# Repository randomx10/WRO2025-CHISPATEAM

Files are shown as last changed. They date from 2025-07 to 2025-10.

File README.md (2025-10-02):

# CHISPA team – WRO 2025
---
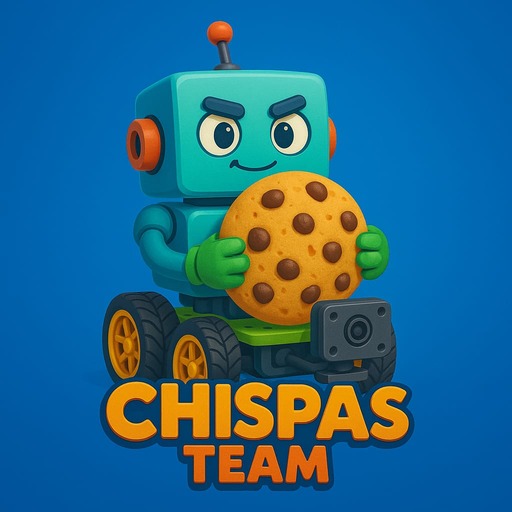
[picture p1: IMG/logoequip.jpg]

---
Welcome to the official repository of the **CHISPA team**!  
This space contains all the resources, schematics, models, photos, and code developed for our participation in the **Future Engineers** challenge at the **World Robot Olympiad 2025**.

>[!NOTE]
>
>Here you’ll find detailed information about the design, functionality, and technical documentation of our autonomous vehicle.
>

---

## 📸 Team Photos

Below are two images that reflect our team’s identity:

| 📷 Official Photo | 😄 Fun Photo |
|---|---|
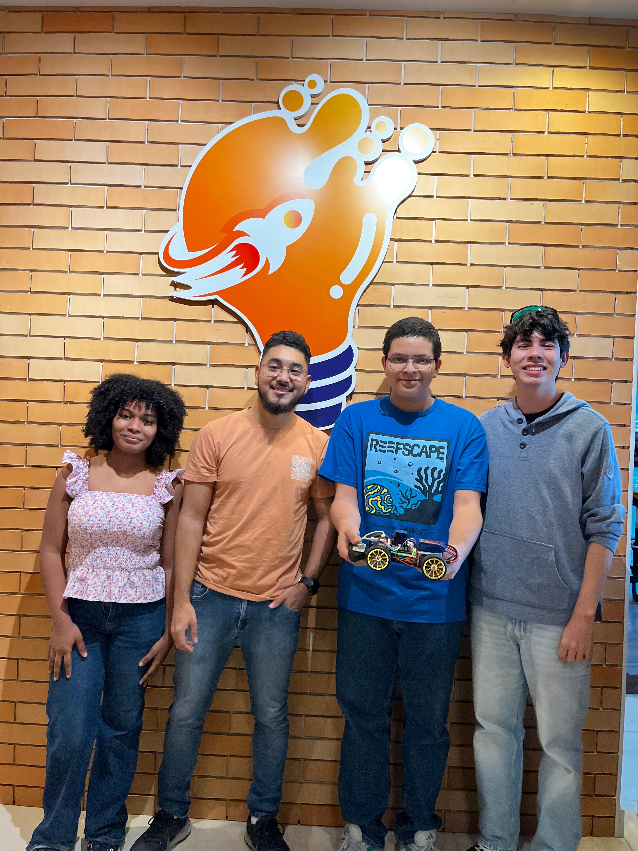
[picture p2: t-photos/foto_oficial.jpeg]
Official team photo
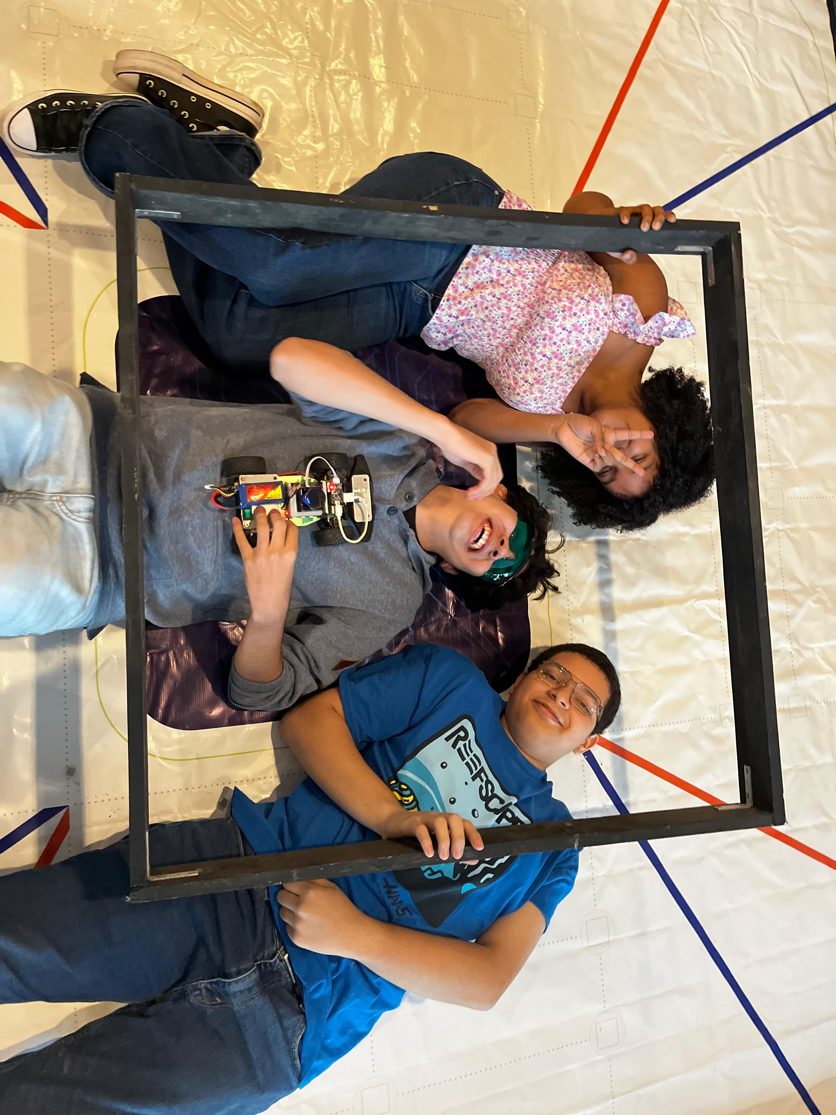
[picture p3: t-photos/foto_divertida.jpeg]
Fun team photo
|  |  |

---

## 💻 Github folder structure/overview
```
🛜 WRO2025-CHISPATEAM
├── 📁 IMG # Images for internal use of the github
├── 📁 docs # Explanation of components/hardware/software
├── 📁 models # 3D parts ready to print
├── 📁 schemes # Schematic diagram of the robot, along with individual component images
├── 📁 src # Source code that powers the robot controllers
├── 📁 t-photos # Team pictures, the funny one and the official
├── 📁 v-photos # All angles of the robot
├── 📁 video # Videos of the robot preforming competition rounds
├── 📄 README.md # Introduction
├── 📄 LICENSE # AGPL 3.0 License Copy, prohibiting copy on other repositories without crediting the respective authors.
├── 📄 equipochis.jpeg # Official team image
```
---

## 🚗 Vehicle View

Here you can see the full design of the vehicle from every angle. This detailed view helps to understand the layout of components and overall structure.

| Front | Back | Left |
|---|---|---|
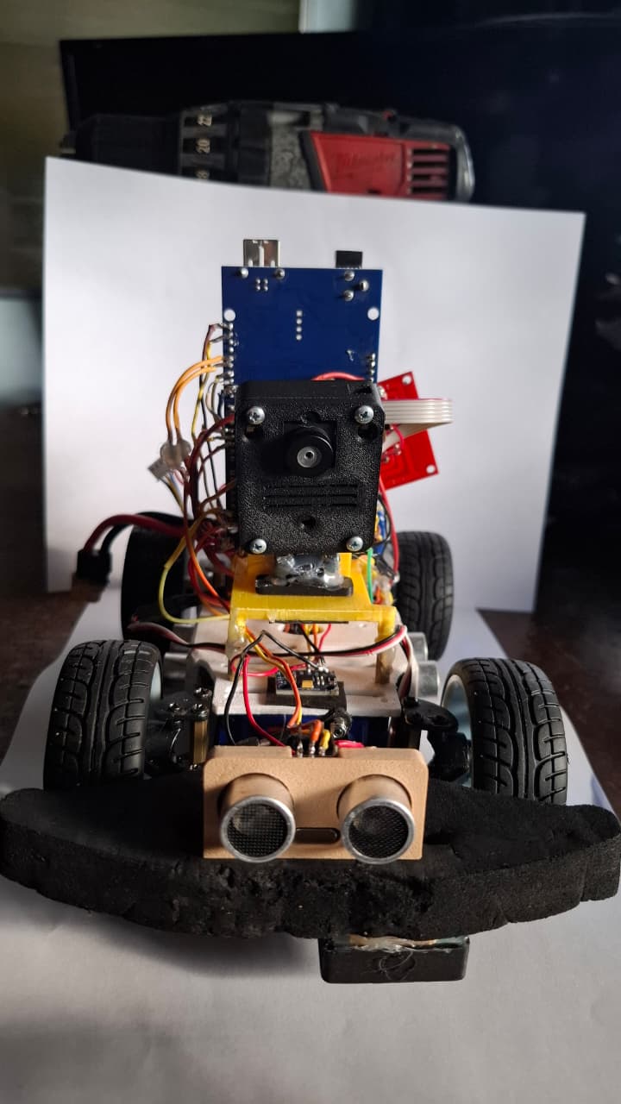
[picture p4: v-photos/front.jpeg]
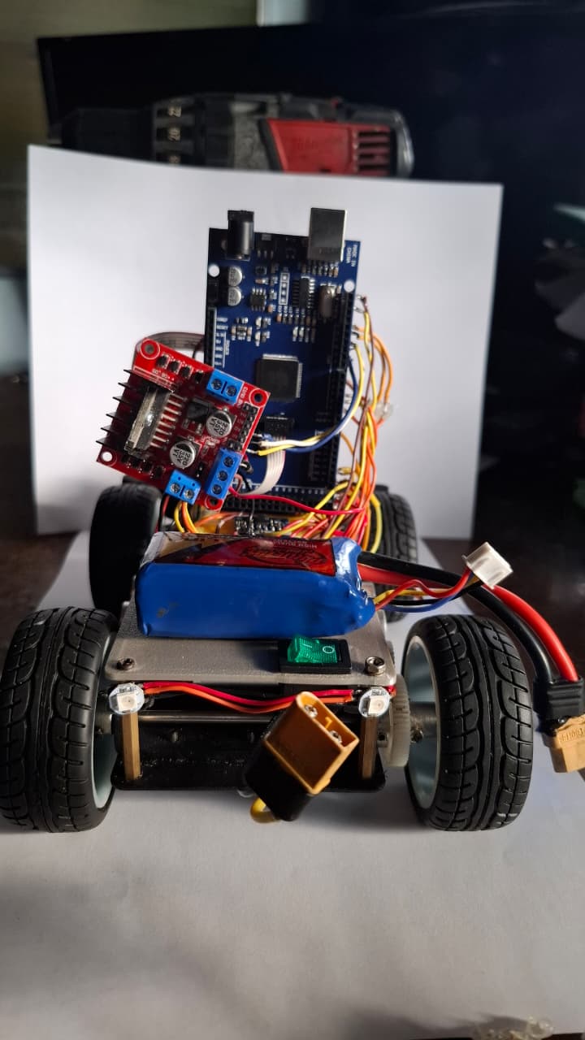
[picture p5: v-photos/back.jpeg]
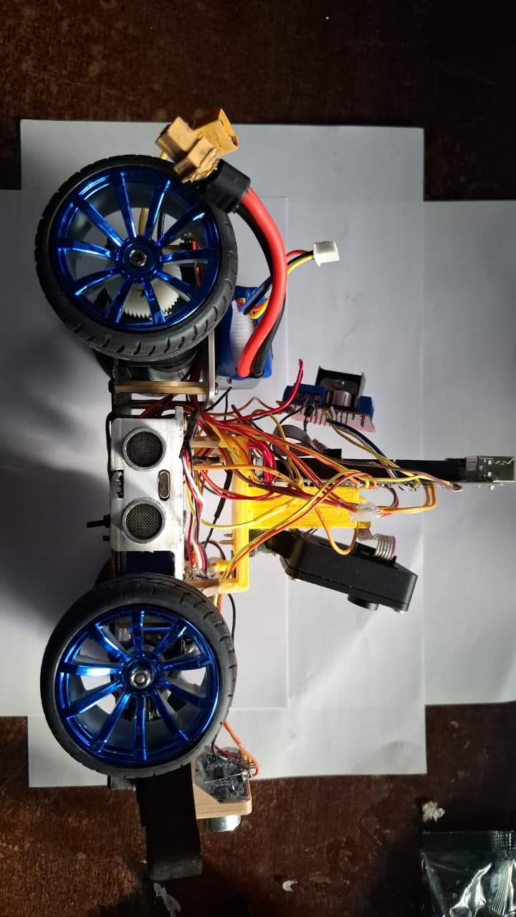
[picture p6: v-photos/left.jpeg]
|  |  |  |

| Right | Top | Bottom |
|---|---|---|
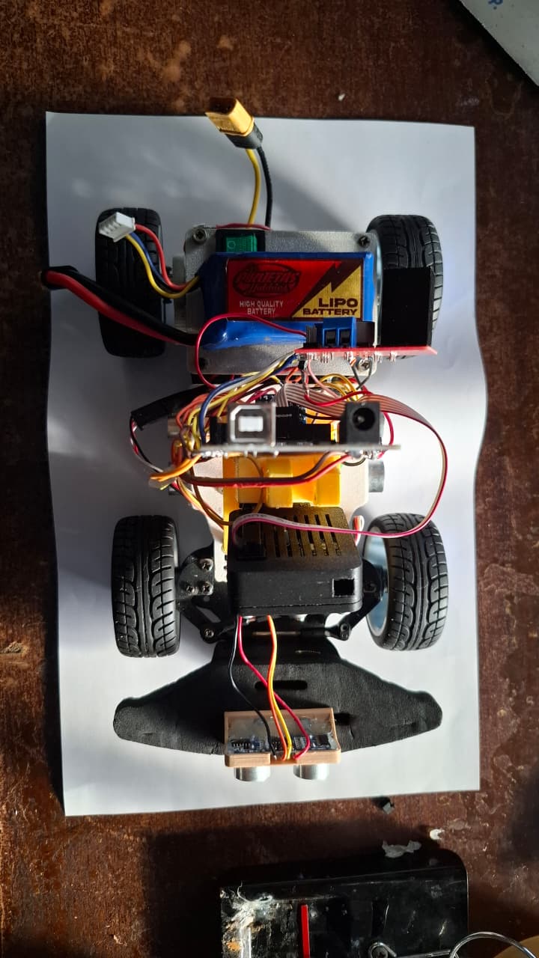
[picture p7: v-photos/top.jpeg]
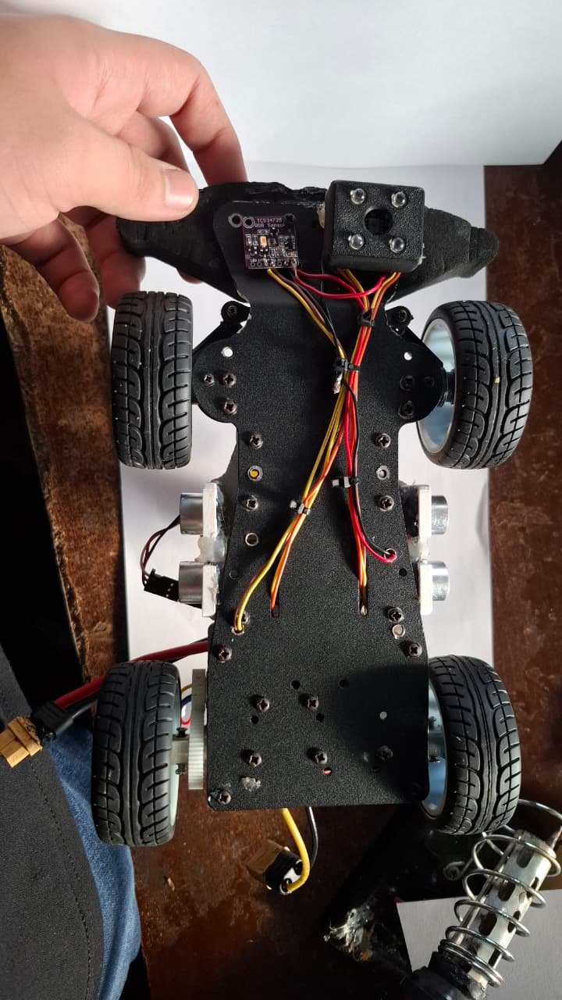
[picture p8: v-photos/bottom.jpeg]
|  |  |  |

---

<h2 align="left">🧠 Electromechanical Components & Wiring</h2>

<table>
  <tr>
    <td align="center">
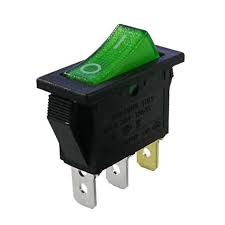
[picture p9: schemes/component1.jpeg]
      <br>
      <b>3-Pin Switch</b>
    </td>
    <td align="center">
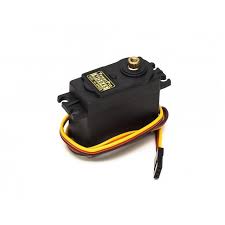
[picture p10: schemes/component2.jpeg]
      <br>
      <b>Servo MG945</b>
    </td>
    <td align="center">
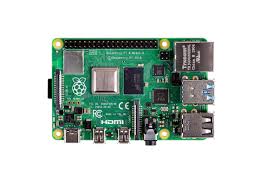
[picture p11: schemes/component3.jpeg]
      <br>
      <b>Raspberry Pi 4</b>
    </td>
  </tr>

  <tr>
    <td align="center">
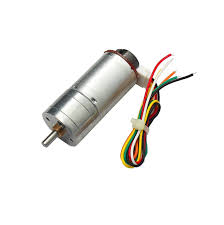
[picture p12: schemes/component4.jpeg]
      <br>
      <b>JGA25-370 Motor</b>
    </td>
    <td align="center">
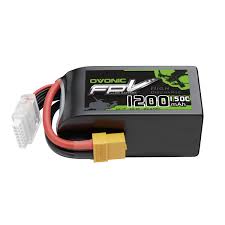
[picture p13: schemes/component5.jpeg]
      <br>
      <b>LiPo Battery 1200mAh 12V</b>
    </td>
    <td align="center">
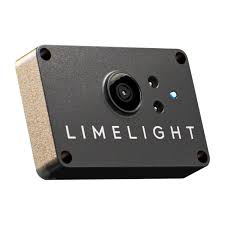
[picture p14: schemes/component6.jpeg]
      <br>
      <b>Limelight 3A</b>
    </td>
  </tr>

  <tr>
    <td align="center">
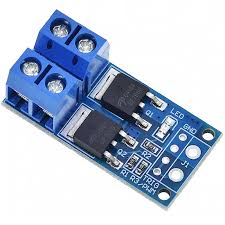
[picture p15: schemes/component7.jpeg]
      <br>
      <b>HC-SR04 Sensor</b>
    </td>
    <td align="center">
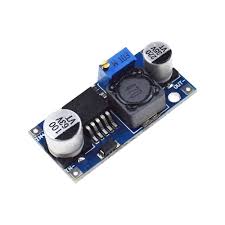
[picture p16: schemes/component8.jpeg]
      <br>
      <b>L298N Motor Driver</b>
    </td>
    <td align="center">
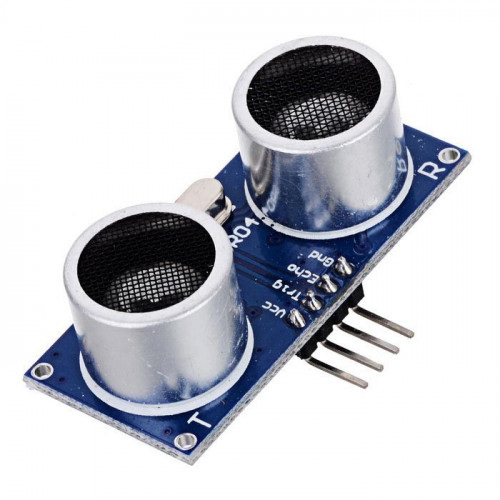
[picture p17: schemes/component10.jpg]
      <br>
      <b>HC-SR04 Sensor</b>
    </td>
  </tr>

  <tr>
    <td align="center">
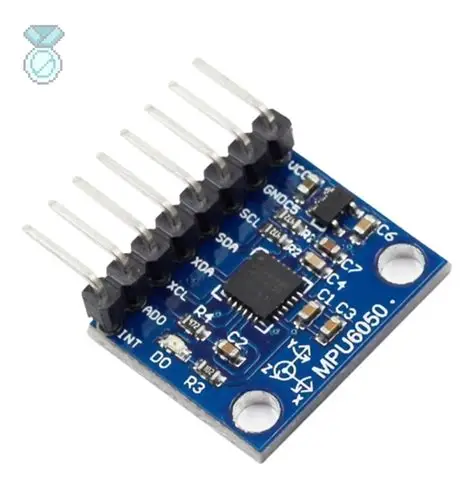
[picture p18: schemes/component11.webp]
      <br>
      <b>GY-251 Gyroscope</b>
    </td>
    <td align="center">
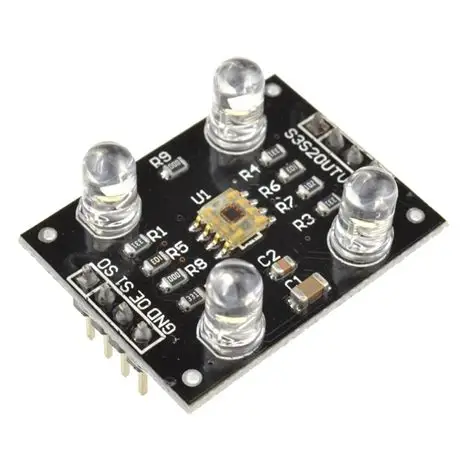
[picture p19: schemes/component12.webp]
      <br>
      <b>TCS3200 Color Sensor</b>
    </td>
    <td align="center">
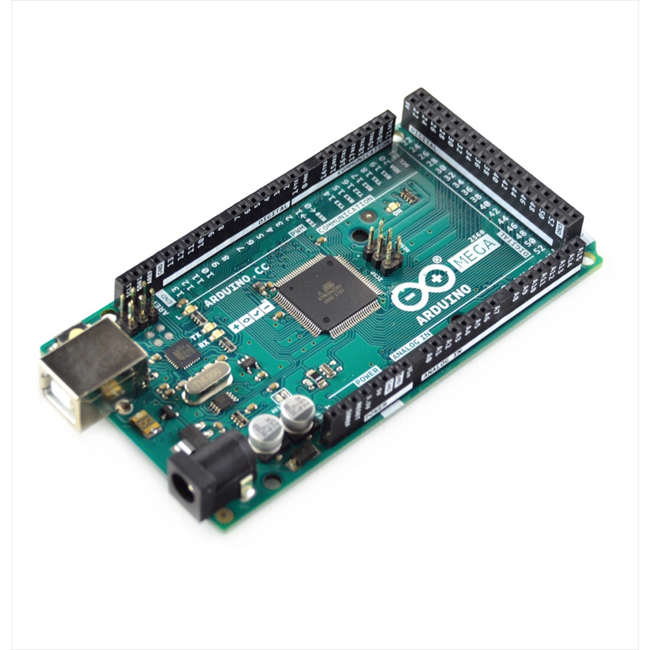
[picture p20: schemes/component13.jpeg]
      <br>
      <b>Arduino Mega</b>
    </td>
  </tr>
</table>

---

### Challenge Overview
The WRO 2025 Future Engineers category challenges student teams to design, build, and program a fully autonomous vehicle capable of navigating a dynamic and randomized racetrack. This vehicle must use sensors, computer vision, and advanced control algorithms to complete multiple laps with high precision. The challenge concludes with a demanding parallel parking maneuver requiring accuracy and control within a confined space 🚗🤖.

### Competition Format
- 🏁 **Open Challenge:** Complete three laps on a track featuring randomly placed inner walls. The vehicle should maintain stable trajectory control, demonstrating robustness and consistent performance throughout.  
- 🚦 **Obstacle Challenge:** Complete three laps while detecting and reacting to randomly placed red and green traffic markers:  
  - 🟥 Red markers require the vehicle to keep to the right side of the lane.  
  - 🟩 Green markers require the vehicle to keep to the left side of the lane.  
  Upon finishing these laps, the vehicle must locate the designated parking zone and execute a precise parallel parking maneuver within limited space 📐.  
- 📑 **Documentation:** Teams must maintain a public repository documenting all aspects of their engineering process, vehicle design, software development decisions, and source code. This provides transparency and demonstrates reproducibility and improved learning.

### Scoring & Evaluation
Judging is based on the following criteria:  
- **Precision:** Accuracy in lap completion, obstacle handling, and parking.  
- **Technical quality:** Clarity, organization, and completeness of project documentation and source code.  
- **Speed:** Total time to complete the challenge, balanced against precision.  
- **Innovation and robustness:** Judges value effective engineering decisions, software reliability, and creative solutions that enhance autonomous performance 💡⚙️.

### Robot Performance: Speed and Maneuvering
Our vehicle's average velocity on straight sections is approximately **1.2 meters per second**, enabling fast and stable lap completion. In contrast, during turns and cornering maneuvers, the speed reduces to about **1.7 meters per second** on average to ensure stable handling and precise navigation. The control algorithm dynamically adapts motor power and steering angles based on sensor feedback, maintaining optimal traction and avoiding drift even in tight curves.

---

### Key Components

| Component | Description |
| --- | --- |
| **Raspberry Pi 4** | Central processor for vision, decision logic, and sensor fusion; runs Python services and serial link to Arduino. |
| **Arduino MEGA** | Real‑time layer for PWM motor drive, servo steering, and ultrasonic reads; ensures deterministic control. |
| **Limelight 3A** | High‑performance vision module adapted for target/color detection to assist navigation and alignment. |
| **HC‑SR04 Ultrasonic Sensors (front + side)** | Proximity sensing and wall following; foam collars reduce ground reflections. |
| **GY‑251 (MPU6050)** | IMU for heading stabilization and consistent 90° turns; mounted near center of gravity. |
| **TCS3200 Color Sensor** | Floor color detection; calibrated for consistent orange/blue under fixed lighting. |
| **L298N Motor Driver** | Dual H‑bridge for direction and PWM speed control; onboard heatsink improves thermal headroom. |
| **JGA25‑370 Gear Motors** | Drive motors with high torque at low RPM for precise maneuvers and climbs. |
| **Servo MG945** | Metal‑gear steering servo; mounted on custom 3D bracket to avoid horn slip. |
| **LiPo 12 V 1200 mAh** | Main power source; sized for match duration with headroom for peaks. |
| **LM2596 Buck Regulator (5 V)** | Stable 5 V rail for logic and sensors; tuned under load to prevent brownouts. |
| **3D‑Printed Chassis** | Lightweight, custom structure with rigid mounts and protected cable routing. |

### Strengths and Innovations
- **Advanced vision processing:** Real-time color and shape detection for robust environment understanding.  
- **Precise sensor fusion:** Combining data from IMU, ultrasonic sensors, and camera enables stable navigation under varying conditions.  
- **Dynamic speed control:** Adapting velocity in straight lines versus curves increases efficiency without sacrificing control.  
- **Modular design:** Easily upgradable hardware and software architecture supports iterative development and rapid testing.  
- **Comprehensive documentation:** Detailed instructions and open-source code improve learning and foster community collaboration.

---

### Index
- [Challenge Overview](#challenge-overview)  
- [Competition Format](#competition-format)  
- [Scoring & Evaluation](#scoring--evaluation)  
- [Robot Performance](#robot-performance-speed-and-maneuvering)  
- [Key Components](#key-components)  
- [Strengths and Innovations](#strengths-and-innovations)  

### 📊 Wiring Diagram

Below is the full electromechanical schematic that shows how everything is connected:

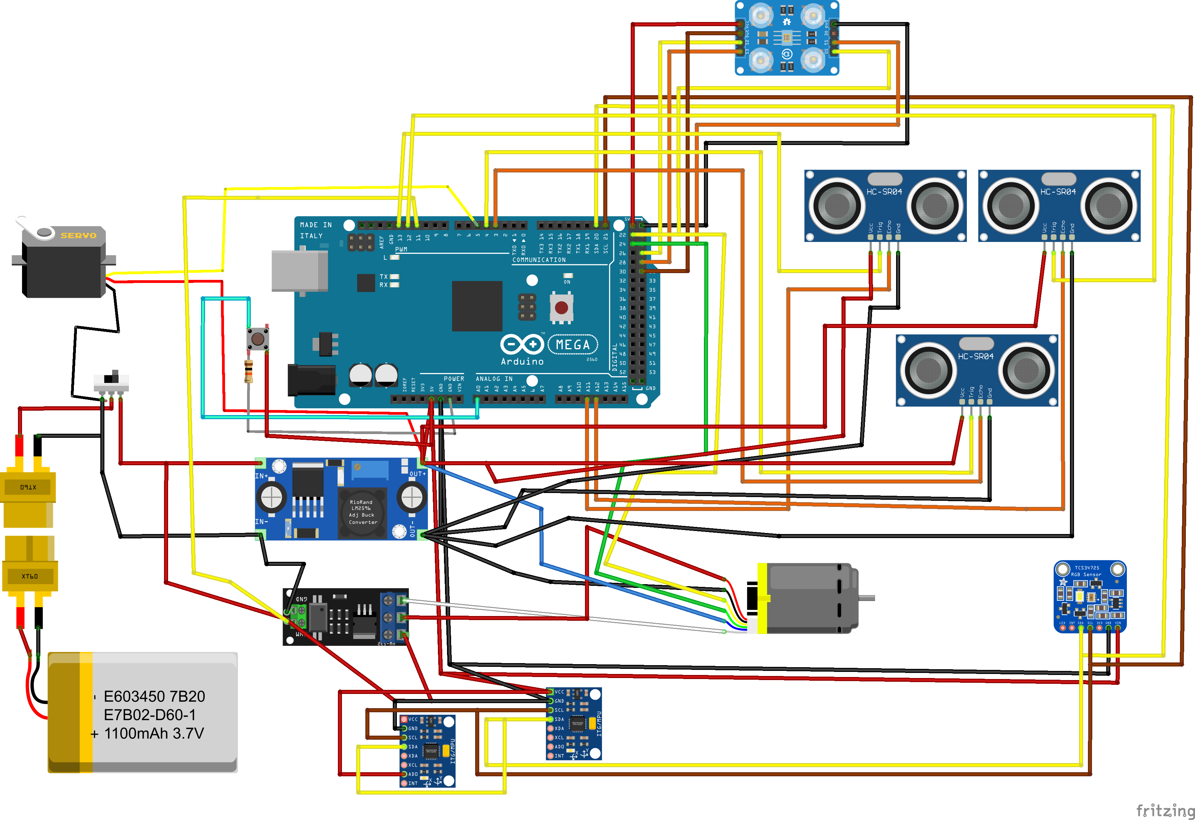
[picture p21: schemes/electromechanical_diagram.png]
Wiring Diagram


> You can find this image and other versions in the [`schemes`](schemes/) folder.

---

## 🔧 Components and Sensor Integration

Our robot was built using a mix of modular components from an existing kit and custom-designed 3D printed parts to fit the needs of the Future Engineers challenge. This hybrid approach allowed us to maximize the strengths of reliable, pre-tested hardware while also tailoring specific solutions for unique tasks in the mission. Below is a highly detailed breakdown of all the components we used, their technical roles, the integration logic, issues we faced, and how we adapted to overcome them. Our documentation not only reflects the functionality of each part, but also highlights the engineering decisions made throughout the robot’s development.

### 🔋 Power Supply 

**LiPo Battery 1200mAh 12V**

- Powers the entire robot system, ensuring both mobility and computational processing are supported throughout the match.  
- Provides stable power output for the motors, sensors, Raspberry Pi, and Arduino.  
- We used a voltage regulator to avoid current spikes and protect delicate components like microcontrollers.  
- This solution helped mitigate early issues we faced with sudden shutdowns during intensive operations.  
- A battery monitor was also incorporated to measure real-time voltage and alert us when levels dropped too low.

### 💻 Main Controllers

**Raspberry Pi 4**

- Acts as the central processing hub of the robot.  
- Responsible for image processing, decision-making logic, and managing sensor data.  
- Runs Python scripts to interpret input from the Limelight and communicates with the Arduino through a serial interface.  
- Its high-speed processing capabilities allow us to manage simultaneous tasks like pathfinding, obstacle avoidance, and turn correction.  

**Arduino MEGA**

- Controls low-level tasks such as PWM motor control and real-time sensor readings (e.g., ultrasonic distance, servo movements).  
- Acts as a reliable bridge for deterministic behavior in the hardware layer.  
- The division of responsibilities between Pi and Arduino helped us balance computational load and reduce latency.  
- Simplifies hardware debugging and guarantees fast, responsive control signals.

### 👁️ Object Detection & Tracking

**Limelight 3A**

- Originally designed for FRC robots, this powerful camera system was adapted to fit our smaller robot.  
- Detects and locks onto specific colored or shaped objects.  
- Enables autonomous navigation by marking visual targets and aligning accordingly.

**Challenges:**  
- Required a well-lit and consistent environment to provide reliable data.  
- We adjusted the robot’s onboard lighting and modified thresholds in the Limelight software to improve reliability.  
- Integrated a protective mount and anti-vibration dampers to stabilize image input.

### 🚫 Removed Component

**LDrobot Lidar LD19**

- Initially selected for real-time SLAM and environment scanning.

**Why We Stopped Using It:**  
- Provided unstable and inconsistent results in small, confined spaces.  
- Difficulty detecting nearby walls and objects due to reflection noise.  
- Calibration proved time-consuming and performance did not justify complexity.

**Our Solution:**  
- Replaced with strategically placed ultrasonic sensors and a reliable gyroscope to manage spatial awareness with much greater efficiency.  
- This switch greatly improved the consistency and reduced computational load.

### 🔄 Motor Control

**L298N Motor Driver**

- Dual H-Bridge driver that allows for direction control and PWM-based speed adjustment.  
- Initial controller suffered overheating; L298N offered a robust and thermally safer alternative.  
- Equipped with a built-in heat sink to improve heat dissipation as this controller gets hot quickly.

**JGA25-370 Gear Motors**

- Provides strong torque and reliable performance, especially during turns and ramp climbs.  
- Compatible with our power source and robust enough for repeated high-load operations.  
- Low RPM ensures accurate control in precision-based movement challenges.

**Servo MG945**

- Handles the turning of the robot left/right.
- Durable metal gears ensure precision and long operational lifespan.  
- Integrated with custom 3D-printed brackets to prevent misalignment and slippage.

### 🔊 Sensors for Navigation and Detection

**HC-SR04 Ultrasonic Sensors**

- Function: Detect distance to nearby objects and walls.  
- Technical Accuracy: ~3mm, max range 4m.  
- Usage: Placed on both front and side of robot to measure proximity and assist in avoiding wall collisions.  
- These sensors play a critical role in maintaining correct lane alignment and determining when to make turns.  
- We added foam dampers around the sensors to reduce interference from ground reflections.

**GY-251 Accelerometer + Gyroscope (MPU6050-based)**

- Function: Detects angular velocity and tilt.  
- Usage: Guides the robot’s heading during turns and confirms straight-line travel.  
- Essential for making consistent 90° turns and for recalibration during complex movements.  
- Mounted at the center of gravity to reduce noise and increase accuracy.

**TCS3200 Color Sensor**

- Function: Reads floor tile colors to guide robot’s path.

**Issues and Solutions:**  
- One unit had significant lag and failed to detect color transitions in motion.  
- Another sensor misidentified multiple colors and only read orange with high confidence.  
- Calibration trials under consistent lighting; replaced the malfunctioning unit with a higher-quality clone.

**Accuracy Reference (sourced from mixed data):**

| Color  | Accuracy (%) |
|---|---|
| Red | 92% |
| Green  | 89% |
| Blue | 94% |
| Yellow | 87% |
| Orange | 96% |
| White  | 91% |
| Black  | 88% |

## (see [docs](https://github.com/randomx10/WRO2025-CHISPATEAM/tree/main/docs) for more information)

### 🔌 Power & Regulation

**LM2596 Voltage Regulator**

- Converts 12V from LiPo battery to stable 5V required by sensors and controllers.  
- Fine-tunable and heat-resistant, preventing power-related failure during operation.  
- Easy to replace and adjust for different output requirements during testing phases.

**3-pin Toggle Switch**

- Allows safe, manual powering of the entire robot without direct battery disconnection.  
- Placed on the back panel for convenient access and safety during handling.

---

## 🛠️ Robot Construction Guide

This guide explains how to assemble the chassis, drivetrain, electronics, and software for the WRO2025-CHISPATEAM robot. Each step is short and practical so the build can be reproduced reliably.

### Step 1: Assemble the steering system ⚙️
- Print the steering-related 3D parts located in `/models` (servo bracket, horn spacer, steering hubs).  
- Mount the Servo MG945 securely to the chassis using screws and the 3D-printed bracket; verify there is no flex under load.  
- Connect the steering axle/linkage to the MG945 horn with a proper coupler; ensure full sweep without binding.  
- Install the front steering hubs and verify the arm moves freely and does not collide with the chassis or wiring.  
- Center the servo (neutral PWM) and align wheels to straight-ahead before tightening horn screws.

### Step 2: Assemble the powertrain 🚗
- Fix the JGA25-370 gear motors onto their 3D-printed motor mounts; use thread-lock where appropriate to prevent loosening.  
- Couple each motor shaft to the driven axle/gear as per the mount design; confirm no eccentricity or wobble.  
- Check clearance so gears and wheels rotate without rubbing the chassis under load.

### Step 3: Mount the electronics 🔌
- Attach the LiPo 12V 1200 mAh battery in a protected position; add foam or straps to avoid vibration and impacts.  
- Install the LM2596 regulator and set a stable 5 V output for logic and sensors; verify with a multimeter before connecting boards.  
- Place the Raspberry Pi 4 and Arduino MEGA on standoffs; route power via LM2596 and keep high-current lines separate from signal lines.  
- Mount the Limelight 3A on a rigid, slightly angled bracket; add anti‑vibration pads to stabilize the image.  
- Position the HC‑SR04 ultrasonic sensors (front and side) with a clear field of view; add small foam skirts if floor reflections are an issue.  
- Mount the GY‑251 (MPU6050) close to the robot’s center of gravity, flat and isolated from motor vibrations.

### Step 4: Attach the wheels 🛞
- Mount front wheels on the steering hubs; ensure free rotation and zero lateral play.  
- Install rear wheels on the driven axle linked to the JGA25‑370; add spacers or washers to maintain alignment.  
- Spin each wheel by hand and listen for rubbing or gear mesh noise; adjust until smooth.

### Step 5: Preparation for operation ✅
- Check that the chassis is balanced and that cable runs are secured away from moving parts.  
- Verify all screw joints are tight; re‑center the servo and confirm steering endpoints do not stall the MG945.  
- Power on with a current‑limited supply the first time; confirm 5 V rail remains stable under sensor and servo load.

### Step 6: Software setup 💻
- On Raspberry Pi 4, deploy the Python services for vision (Limelight integration), decision logic, and Pi↔Arduino serial link.  
- On Arduino MEGA, upload the low‑level firmware handling PWM motor control, servo steering and real‑time sensor reads.  
- Test the serial protocol: the Pi should stream targets/commands, the MEGA should acknowledge and actuate deterministically.  
- Calibrate sensors:  
  - Limelight thresholds/lighting profile.  
  - Ultrasonic baselines and timeouts.  
  - MPU6050 gyro bias at rest.  
- Run a dry test on blocks (wheels off the ground) to validate direction, steering sign, and emergency stop.

---

## 🧠 How It All Works Together

Our robot was developed for the WRO 2025 Future Engineers Challenge, a task requiring navigation of a color-coded maze, obstacle avoidance, and accurate maneuvering. To achieve this, we implemented a layered control strategy:

**Color Sensing:**  
- The robot follows a line/path system on the floor, detecting color patterns using the TCS3200.  
- Decisions (turns, stops, or interactions) are triggered based on detected color.  
- Logic is reinforced with timeouts and counters to avoid misreads from transient reflections.

**Obstacle Avoidance:**  
- HC-SR04 sensors measure distances in real-time.  
- On detecting an object or wall within a threshold, the robot adjusts trajectory accordingly.  
- In edge cases, the gyroscope is consulted to determine alternative safe paths.

**Turning & Direction Control:**  
- Using GY-251 gyro data, we ensure consistent 90° turns.  
- Helps correct drift and ensures we remain aligned with map paths.  
- Combined with encoder data for better positional awareness.

**Central Coordination:**  
- The Raspberry Pi processes high-level logic and forwards simplified instructions to the Arduino.  
- This modular separation allows real-time reaction to environmental data while executing long-term movement plans.  
- Logs are stored locally for later debugging and performance analysis.

**Structural Customization:**  
- We modified kit-based chassis with 3D-printed mounts for better sensor placement and airflow.  
- This helped avoid overheating and mechanical misalignments during long test sessions.  
- The design is compact yet expandable, making it ideal for future missions.

**Component Testing and Iteration:**  
- Every part of the robot went through unit testing and stress evaluation.  
- We documented all observed limitations and iteratively improved sensor placement and code logic.  
- Testing environments included both simulated and real-field trials.

By overcoming major hurdles like sensor inconsistency, voltage fluctuations, and Lidar misreadings, we developed a system that is adaptive, stable, and ready to complete the mission using components we understand deeply. Our documentation, design, and testing reflect a clear engineering vision with flexibility and resilience at its core.

In summary, the robot reflects a balance between innovation and practicality — leveraging what we have while adapting smartly to meet the demands of a complex and evolving challenge. Our engineering choices were made with precision, and the modular approach means the robot is easy to repair, extend, and reconfigure if necessary. We’re proud of its development and look forward to testing it further on the competition field.

<h2 align="left">🧩 3D Printed Parts</h2>

<p>
In this section, you will find the 3D printed components that were essential to the design and functionality of our robot. These pieces were specifically created to optimize vision and structural support while keeping the overall weight of the robot low and ensuring precise alignment of key systems.
</p>

<table>
  <tr>
    <td align="center">
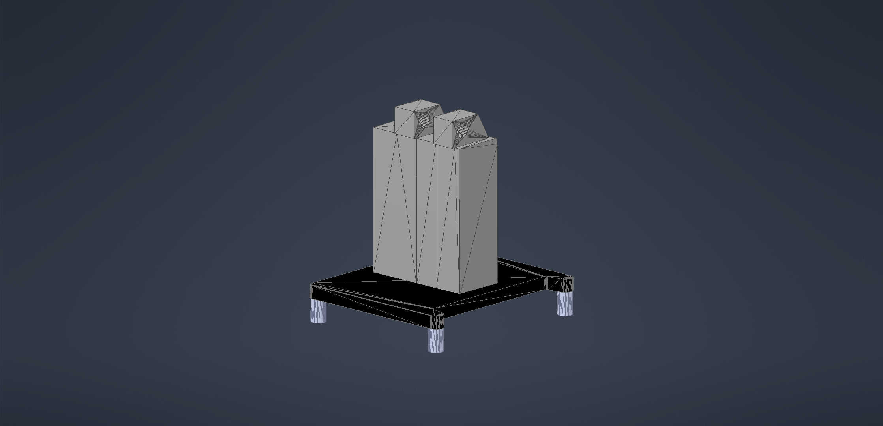
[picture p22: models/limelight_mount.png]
      <br>
      <b>Limelight Mount</b><br>
      One of the most important printed pieces is the mount for the Limelight camera. We designed it to keep the vision system stable and in the right position to detect the traffic signals and track targets efficiently. The angle was carefully adjusted to increase field of view and reduce blind spots. It’s lightweight but solid enough to hold the camera steady, even during fast movements. This improvement helped us gain more accuracy and align much better with our objectives.
    </td>
    <td align="center">
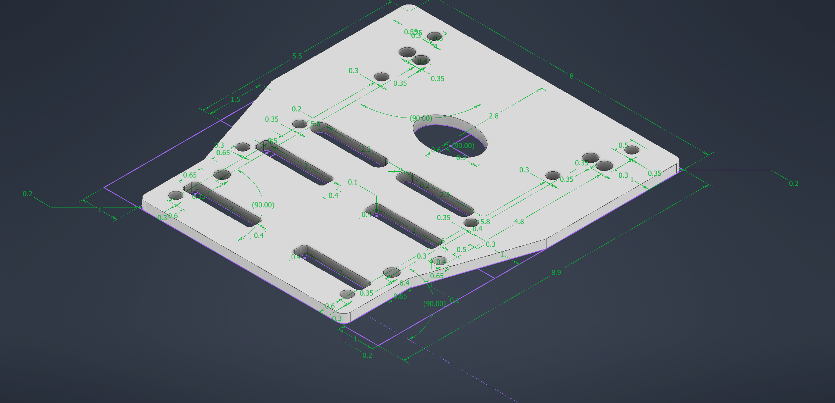
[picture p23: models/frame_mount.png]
      <br>
      <b>Top Chassis Support</b><br>
      This structural support is placed on the top part of the chassis and was designed to hold sensors, wiring, and additional modules in place. One of the main goals was to improve the internal layout of the robot, keeping everything organized and making maintenance easier. It also adds an extra layer of protection to the internal electronics. This part was printed using strong filament to ensure rigidity and durability, without affecting the balance of the robot.
    </td>
  </tr>
</table>

<p>
Both of these components were modeled in CAD software and tested through multiple iterations before reaching the final versions. The printing process took several hours for each, but the result was worth the effort, as they improved our performance significantly during testing and competition.
</p>

## 🎯 Competition Challenges

<table align="center" border="1" cellspacing="0" cellpadding="8">
  <tr>
    <!-- Open Challenge card -->
    <td valign="top" width="360">
      <div>🔗 Open Challenge</div>
      <div align="center">
        Open Challenge - image
      </div>
      <div align="center">
        <a href="https://www.youtube.com/watch?v=e4CDzBtp_W8">Watch Open Challenge Round</a>
      </div>
    </td>
  </tr>
</table>

##  Track Performance

Our vehicle is tuned for stable, repeatable lap times by adapting speed and steering to the track segment: it targets approximately 1.2 m/s on straight sections and about 1.7 m/s through turns, with smooth ramp-up and ramp-down around each corner to preserve traction and heading control.

#### Key metrics
- Straight-line speed: ~1.2 m/s, with high-frequency heading corrections to stay centered in the lane.
- Cornering speed: ~1.7 m/s, limited by lateral acceleration and line-of-sight constraints near inner walls.
- Transitions: short acceleration/brake ramps before/after the apex to avoid over/understeer.
- Stability: yaw-based PD keeps the car aligned; exit lines are corrected quickly after each corner.

| Parameter | Straights | Turns |
| :--- | :--- | :--- |
| Target speed | ~1.2 m/s | ~1.7 m/s |
| Primary control | Gyro-based PD (yaw)  | Gyro PD + lateral accel cap |
| Acceleration | Smooth, traction-first | Suppressed at apex, recover on exit |
| Corrections | Small, high-rate | Moderate, radius-dependent |

#### How it works
- Pre-aiming into corners: the controller slightly reduces speed and applies steering in advance so the vehicle is already stable at corner entry.  
- Lateral acceleration limiter: while cornering, the controller caps lateral demand; if heading error rises, it briefly trims speed to regain grip.  
- Corner exit: past the apex, the system straightens steering and restores speed to the 1.2 m/s target, prioritizing a clean trajectory over peak thrust.  
- Line and wall biasing: near inner walls, the lateral offset is adjusted to keep safe clearance without adding unnecessary steering oscillations.

#### Measurement assumptions
- Test track uses standard surface and markings; tires are calibrated and warmed up.
- The 1.2 m/s (straights) and 1.7 m/s (turns) targets can vary slightly with temperature, tire wear, and lighting.
- Practice sessions should log section times to verify consistency; comparing segment splits is recommended for tuning.

> [!WARNING]
>
> This program is distributed in the hope that it will be useful,
> but WITHOUT ANY WARRANTY; without even the implied warranty of
> MERCHANTABILITY or FITNESS FOR A PARTICULAR PURPOSE.
> If any portion of this program is to be used in any other application, you must
> credit the respective authors and provide a copy of the AGPL 3.0 License.
> [More information on LICENSE.](https://github.com/randomx10/WRO2025-CHISPATEAM/blob/main/LICENSE)
>

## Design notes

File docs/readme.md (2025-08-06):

# 🤖 Project CHISPA: Components & Sensor Integration

Welcome to the documentation for **Project CHISPA**, our robot designed for the WRO 2025 Future Engineers Challenge! This README provides an in-depth look at the hardware that powers our autonomous system, detailing each component's role, integration logic, and the engineering challenges we overcame during development.

Our robot leverages a **hybrid approach**, combining robust modular components from an existing kit with custom-designed 3D-printed parts. This strategy allowed us to harness the reliability of pre-tested hardware while creating tailored solutions for the mission's unique demands.

## 🗺️ Table of Contents

1. [🔋 Power Supply]

2. [💻 Main Controllers]

3. [👁️ Object Detection & Tracking]

4. [🚫 Removed Component: Lidar]

5. [🔄 Motor Control]

6. [🔊 Sensors for Navigation and Detection]

7. [🔌 Power & Regulation]

8. [🧠 How It All Works Together]

## 🔋 Power Supply

The backbone of our robot's operation, ensuring consistent power delivery to all systems.

* **LiPo Battery 1200mAh 12V**

  * **Role:** Powers the entire robot, supporting both mobility and computational processing throughout the mission.

  * **Integration Logic:** Provides stable power output for motors, sensors, Raspberry Pi, and Arduino.

  * **Key Feature:** We Integrated a **voltage regulator** to prevent current spikes and protect delicate components, it is the LM2596 which provides us with stable 12V to 5V for the raspberry pi, arduino, servo and sensors.
 
  * **Issue & Solution:** Mitigated early issues of sudden shutdowns during intensive operations. A **battery monitor** was incorporated for real-time voltage measurement and low-level alerts.

## 💻 Main Controllers

The brains and brawn, orchestrating high-level decision-making and low-level hardware control.

* **Raspberry Pi 4**

  * **Role:** Central processing hub. Responsible for **image processing**, **decision-making logic**, and **sensor data management**.

  * **Integration Logic:** Runs Python scripts to interpret input from the Limelight and communicates with the Arduino via a serial interface.

  * **Capabilities:** High-speed processing for simultaneous tasks like pathfinding, obstacle avoidance, and turn correction.

  * **Enhancements:** Includes an **external cooling fan** and **heat sinks** for optimal temperature maintenance during extended operations.

* **Arduino MEGA**

  * **Role:** Controls low-level tasks such as **PWM motor control** and **real-time sensor readings** (e.g., ultrasonic distance, servo movements).

  * **Integration Logic:** Acts as a reliable bridge for deterministic behavior in the hardware layer such as the drivetrain itself (servomotor and engine).

  * **Benefits:** Division of responsibilities with the Pi balances computational load and reduces latency. Simplifies hardware debugging and guarantees fast, responsive control signals.

## 👁️ Object Detection & Tracking

Our robot's eyes, enabling autonomous navigation through visual target acquisition.

* **Limelight 3A**

  * **Role:** Powerful camera system adapted from FRC robots to detect and lock onto specific colored or shaped objects.

  * **Usage:** Enables autonomous navigation by marking visual targets and aligning the robot accordingly.

  * **Challenges:**

    * Required a well-lit and consistent environment for reliable data.

    * **Solution:** Adjusted the robot’s onboard lighting and modified thresholds in the Limelight software to improve reliability.

    * **Solution:** Integrated a **protective mount** and **anti-vibration dampers** to stabilize image input.

## 🚫 Removed Component: LDrobot Lidar LD19

An initial consideration for environmental mapping that was ultimately replaced.

* **LDrobot Lidar LD19**

  * **Initial Purpose:** Selected for real-time SLAM (Simultaneous Localization and Mapping) and environment scanning.

  * **Why We Stopped Using It:**

    * Provided unstable and inconsistent results in small, confined spaces (the LIDAR worked better in way more open fields up to 12m).

    * Difficulty detecting nearby walls and objects due to reflection noise (plots randomly appeared and then stopped appearing after a second or two, making it impossible to do multiple sampling).

    * Calibration proved time-consuming, and performance did not justify the complexity and time required to get it working.

  * **Our Solution:** Replaced with strategically placed **ultrasonic sensors** and a reliable **gyroscope** to manage spatial awareness with much greater efficiency. This switch significantly improved consistency and reduced computational load.

## 🔄 Motor Control

Driving the robot's movement with precision and power.

* **L298N Motor Driver**

  * **Role:** Dual H-Bridge driver allowing for **direction control** and **PWM-based speed adjustment**.

  * **Issue & Solution:** Initial controller suffered overheating; the L298N offered a robust and thermally safer alternative. Equipped with a **built-in heat sink** to improve heat dissipation.

* **JGA25-370 Gear Motors**

  * **Role:** Provide strong torque and reliable performance, especially during turns and ramp climbs (**yes, this is a problem at regionals, theres quite literally speedbumps**).

  * **Features:** Compatible with our power source and robust enough for repeated high-load operations. High RPM ensures a lot of speed and the integrated encoder ensures accurate control in precision-based movement challenges such as the obstacle round.

* **Servo MG945**

  * **Role:** Handles the system that allows the car to turn left/right.

  * **Features:** Durable metal gears ensure precision and a long operational lifespan.

  * **Integration:** Integrated with custom **3D-printed brackets** to prevent misalignment and slippage.

## 🔊 Sensors for Navigation and Detection

The robot's senses, crucial for understanding its environment and navigating the challenge course.

* **HC-SR04 Ultrasonic Sensors**

  * **Function:** Detect distance to nearby objects and walls.

  * **Technical Accuracy:** \~3mm, max range 4m.

  * **Usage:** Placed on both the front and side of the robot to measure proximity and assist in avoiding wall collisions. Critical for maintaining correct lane alignment and determining turn timings.

  * **Enhancement:** Added **foam dampers** around the sensors to reduce interference from ground reflections.

* **GY-251 Accelerometer + Gyroscope (MPU6050-based)**

  * **Function:** Detects angular velocity and tilt.

  * **Usage:** Guides the robot’s heading during turns and confirms straight-line travel. Essential for consistent 90° turns and recalibration during complex movements.

  * **Placement:** Mounted at the **center of gravity** to reduce noise and increase accuracy.

* **TCS3200 Color Sensor**

  * **Function:** Reads floor tile colors to guide the robot’s path.

  * **Issues and Solutions:**

    * One unit had significant lag and failed to detect color transitions in motion.

    * Another sensor misidentified multiple colors and only read orange with high confidence.

    * **Solution:** Performed extensive **calibration trials** under consistent lighting; replaced the malfunctioning unit with a higher-quality clone.

  **Accuracy Reference (sourced from our own research):**
Graph1

## 🔌 Power & Regulation

Ensuring stable and safe power distribution throughout the system.

* **LM2596 Voltage Regulator**

  * **Role:** Converts 12V from the LiPo battery to a stable 5V required by sensors and controllers.

  * **Features:** Fine-tunable and heat-resistant, preventing power-related failures. Easy to replace and adjust for different output requirements during testing phases.

* **3-pin Toggle Switch**

  * **Role:** Allows safe, manual powering of the entire robot without direct battery disconnection.

  * **Placement:** Placed on the back panel for convenient access and safety during handling.

## 🧠 How It All Works Together

Our robot was developed for the WRO 2025 Future Engineers Challenge, which requires navigating a color-coded maze, obstacle avoidance, and accurate maneuvering. We implemented a **layered control strategy** to achieve these objectives:

* **Color Sensing for Path Following:**

  * The robot follows a line/path system on the floor, detecting color patterns using the TCS3200.

  * Decisions (turns, stops, or interactions) are triggered based on detected colors.

  * Logic is reinforced with timeouts and counters to avoid misreads from transient reflections.

* **Dynamic Obstacle Avoidance:**

  * HC-SR04 sensors measure distances in real-time.

  * Upon detecting an object or wall within a predefined threshold, the robot adjusts its trajectory accordingly.

  * In edge cases, the gyroscope is consulted to determine alternative safe paths.

* **Precise Turning & Direction Control:**

  * Using GY-251 gyroscope data, we ensure consistent 90° turns.

  * This helps correct drift and ensures the robot remains aligned with mapped paths.

  * Combined with encoder data for enhanced positional awareness.

* **Centralized Coordination (Pi-Arduino Synergy):**

  * The **Raspberry Pi** processes high-level logic and forwards simplified instructions to the **Arduino**.

  * This modular separation allows for real-time reaction to environmental data while executing long-term movement plans.

  * Logs are stored locally for later debugging and performance analysis.

* **Structural Customization & Optimization:**

  * We modified kit-based chassis with **3D-printed mounts** for better sensor placement and airflow.

  * This helped avoid overheating and mechanical misalignments during long test sessions.

  * The design is compact yet expandable, making it ideal for future missions.

* **Rigorous Component Testing and Iteration:**

  * Every part of the robot underwent unit testing and stress evaluation.

  * We documented all observed limitations and iteratively improved sensor placement and code logic.

  * Testing environments included both simulated and real-field trials.

### 🌟 Conclusion

By meticulously overcoming major hurdles like sensor inconsistency, voltage fluctuations, and Lidar misreadings, we developed a system that is **adaptive, stable, and highly capable** of completing the mission. Our documentation, design, and testing reflect a clear engineering vision with flexibility and resilience at its core.

Project CHISPA embodies a balance between innovation and practicality — leveraging existing resources while smartly adapting to meet the demands of a complex and evolving challenge. Our engineering choices were made with precision, and the modular approach ensures the robot is easy to repair, extend, and reconfigure if necessary. We’re proud of its development and look forward to its performance on the competition field!

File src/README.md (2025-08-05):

Control software
====

This directory contains code for control software which is used by the vehicle to participate in the competition, it contains a mix of a self made LIDAR library for detection of objects using the LDROBOT LD19 lidar and the current code for the robot in main.ino

The code is mostly written in c++ and handles the PWM output for servos, engines, and inputs such as the ultrasonic sensors, the color sensors and the gyroscope which is an essential part of the code as it used a PID to autocorrect steep angles and keep itself straight.

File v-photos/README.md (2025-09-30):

<h2 align="center">Vehicle's Photos</h2>

<table>
  <tr>
    <th>Front</th>
    <th>Right</th>
    <th>Back</th>
  </tr>
  <tr>
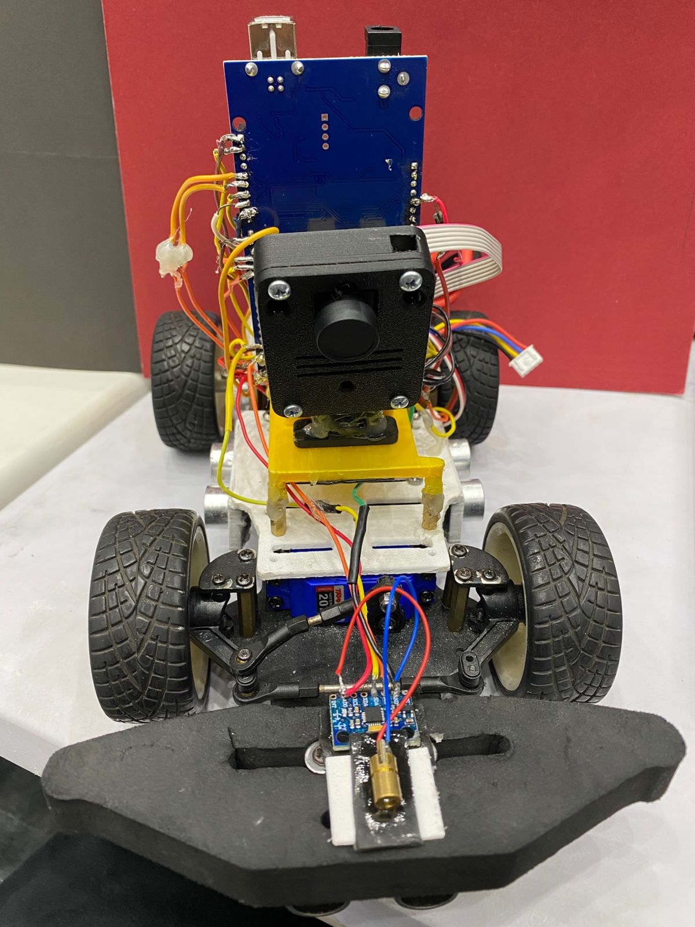
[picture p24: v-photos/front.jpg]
    <td></td>
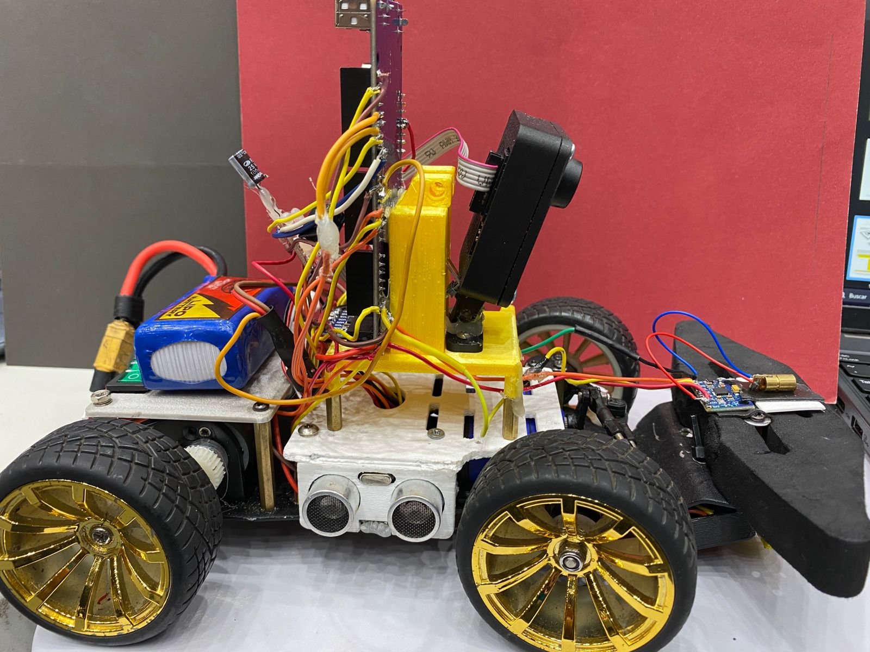
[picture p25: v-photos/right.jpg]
    <td></td>
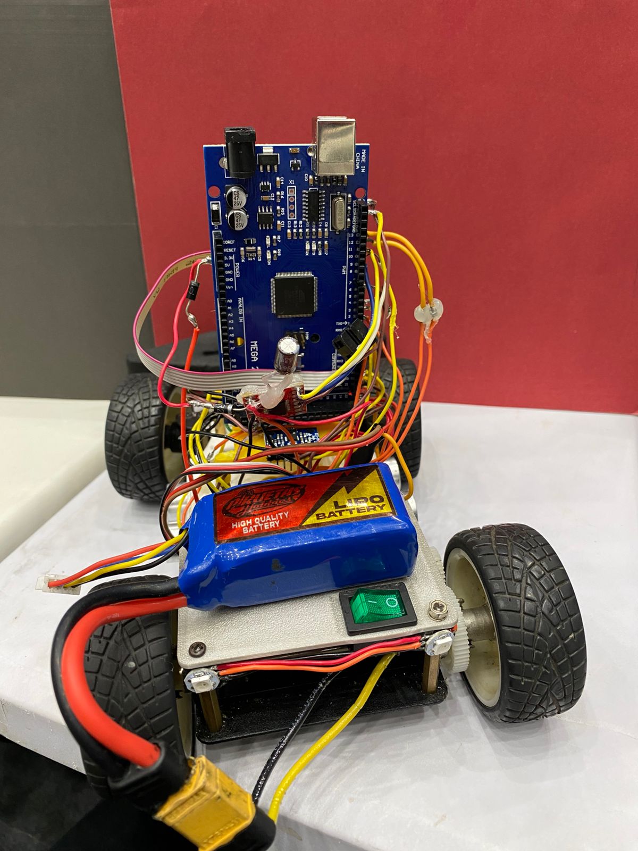
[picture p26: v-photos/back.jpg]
    <td></td>
  </tr>
  <tr>
    <th>Left</th>
    <th>Top</th>
    <th>Bottom</th>
  </tr>
  <tr>
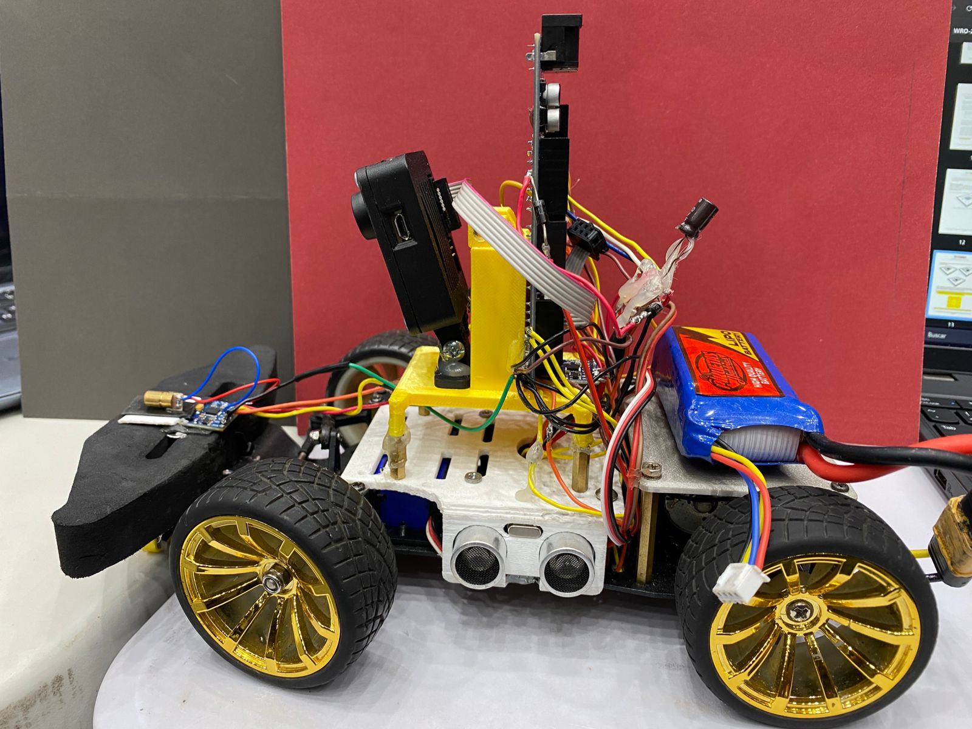
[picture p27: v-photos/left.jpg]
    <td></td>
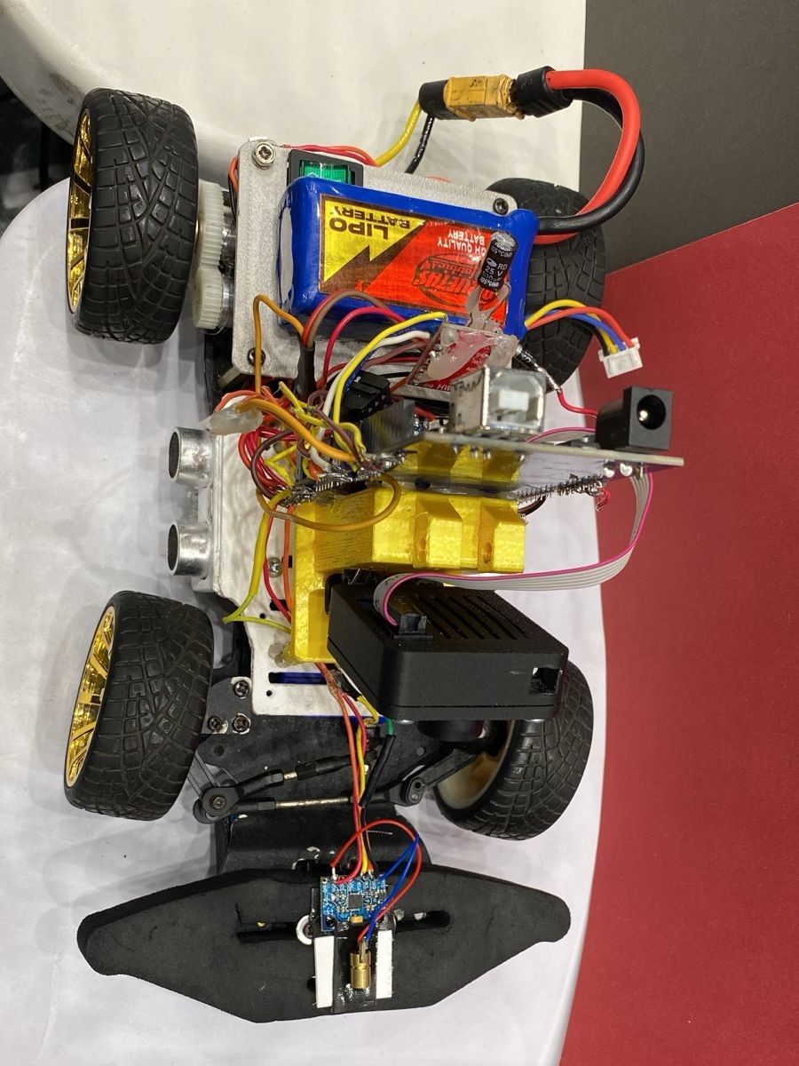
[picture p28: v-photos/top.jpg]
    <td></td>
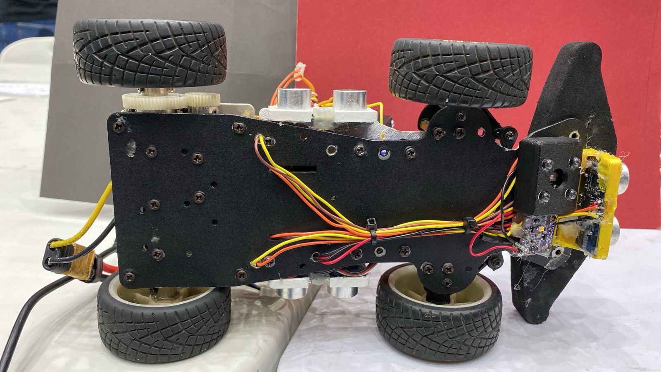
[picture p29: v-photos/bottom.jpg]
    <td></td>
  </tr>
</table>

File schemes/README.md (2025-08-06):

Electromechanical diagrams
====

This directory contains most component images and the electronic diagram of our robot.
---

---

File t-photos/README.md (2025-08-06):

Team's photos
---

---

---

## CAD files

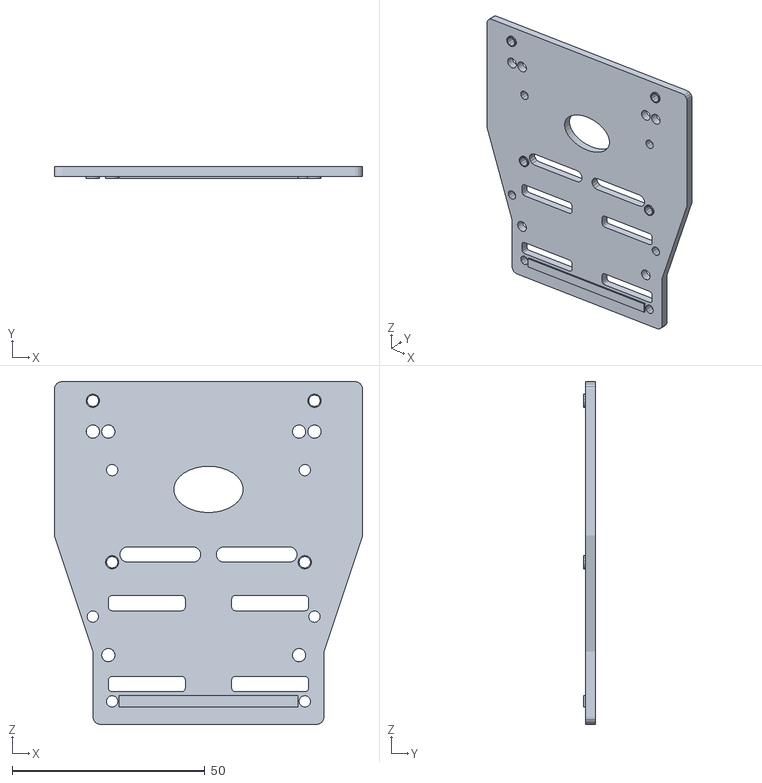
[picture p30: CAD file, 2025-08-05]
models/center.stl
80.0 x 3.00 x 89.0

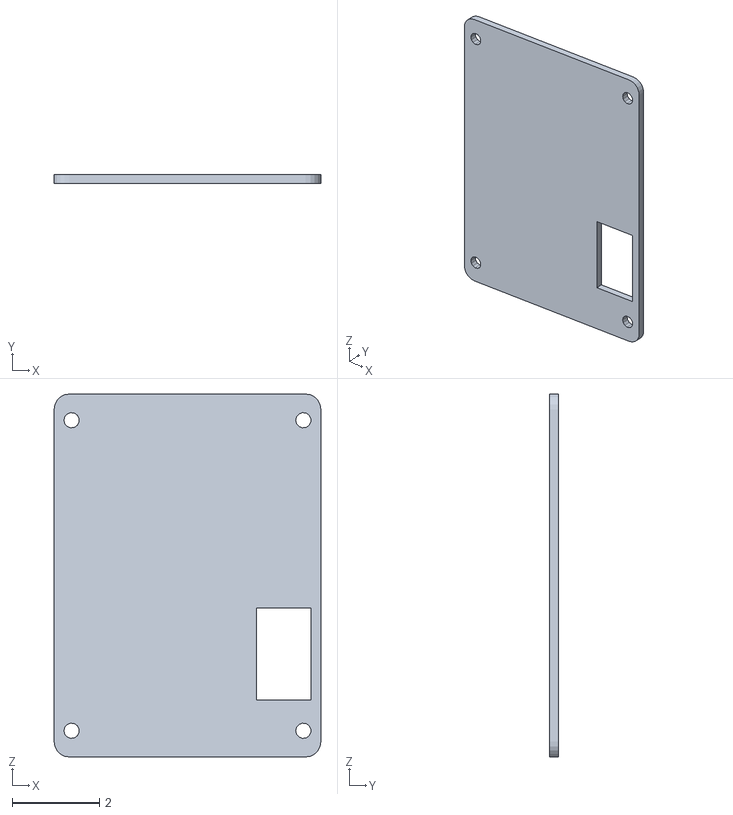
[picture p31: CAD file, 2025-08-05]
models/back.stl
6.10 x 0.2 x 8.30

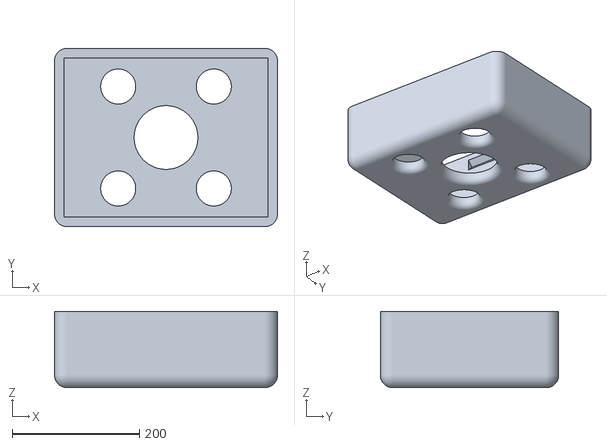
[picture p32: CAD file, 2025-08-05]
models/color sensor case.stl
350.0 x 280.0 x 120.0

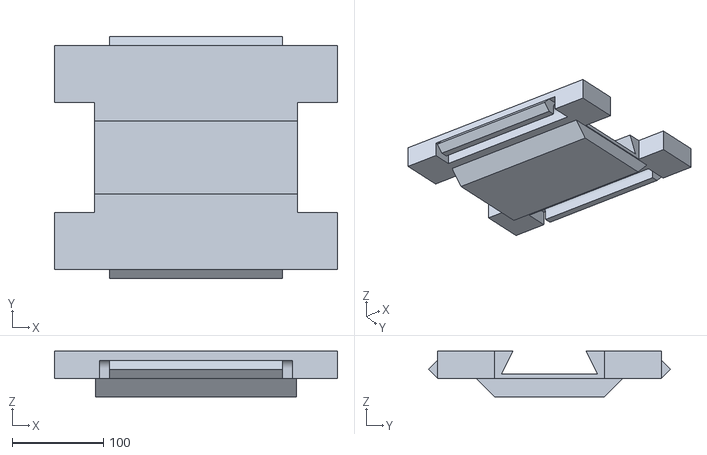
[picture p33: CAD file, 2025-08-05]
models/color sensor case top.stl
310.0 x 265.0 x 50.0

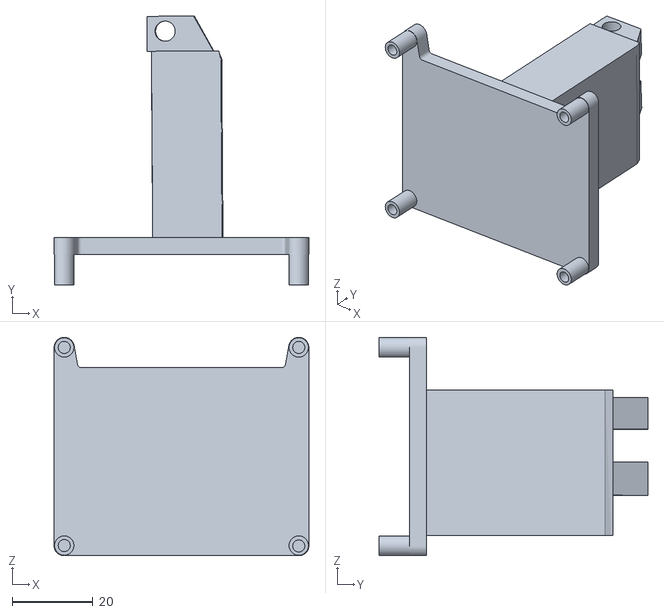
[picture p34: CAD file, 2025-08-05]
models/bracket limelight v2.stl
63.0 x 66.5 x 54.0

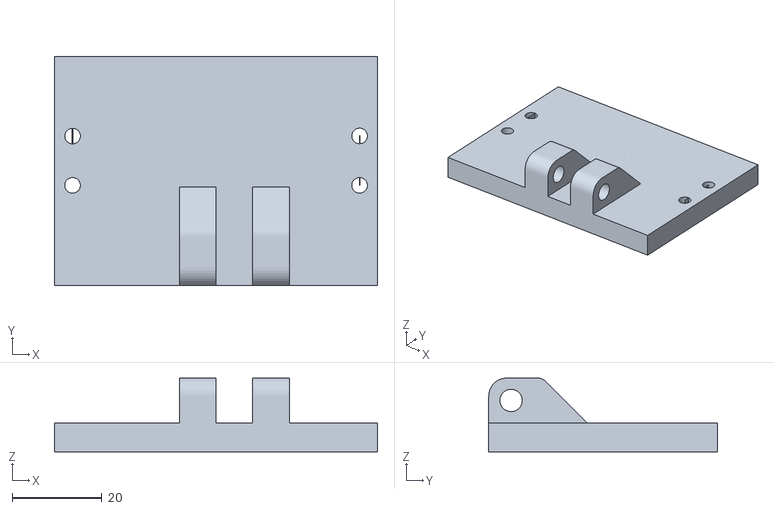
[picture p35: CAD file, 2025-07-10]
models/limelight beta.stl
72.1 x 51.0 x 16.5

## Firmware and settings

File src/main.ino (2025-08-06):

/*
    Copyright (C) 2025  Alexis Martinez

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
    You should have received a copy of the GNU Affero General Public License
    along with this program.  If not, see <https://www.gnu.org/licenses/>.
*/

/*
 * WRO Future Engineers Robot Controller
 * Arduino Mega 2560 with TCS3200 RGB sensor and advanced navigation
 * 
 * Hardware Configuration:
 * - TCS3200 RGB Sensor: S0=23, S1=25, S2=27, S3=29, OUT=31
 * - MPU6050 IMU: SDA=20, SCL=21
 * - Left Distance Sensor: TRIG=13, ECHO=A11
 * - Right Distance Sensor: TRIG=12, ECHO=A12
 * - Front Distance Sensor: TRIG=4, ECHO=3
 * - Drive Motor: PWM=11
 * - Wheel Encoder: A=22, B=24
 * - Steering Servo: PWM=5
 * - NeoPixel Status: PIN=8, COUNT=2
 */

#include <Wire.h>
#include <Adafruit_MPU6050.h>
#include <Adafruit_Sensor.h>
#include <Servo.h>
#include <Adafruit_NeoPixel.h>

// ===== HARDWARE PIN ASSIGNMENTS =====
// TCS3200 RGB Color Sensor
#define RGB_S0_PIN    23
#define RGB_S1_PIN    25
#define RGB_S2_PIN    27
#define RGB_S3_PIN    29
#define RGB_OUT_PIN   31

// MPU6050 Inertial Measurement Unit
#define IMU_SDA_PIN   20
#define IMU_SCL_PIN   21

// HC-SR04 Distance Sensors
#define DIST_LEFT_TRIG  13
#define DIST_LEFT_ECHO  A11
#define DIST_RIGHT_TRIG 12
#define DIST_RIGHT_ECHO A12
#define DIST_FRONT_TRIG 4
#define DIST_FRONT_ECHO 3

// Actuators and Feedback
#define DRIVE_MOTOR_PIN 11
#define STEERING_SERVO_PIN 5
#define ENCODER_PHASE_A 22
#define ENCODER_PHASE_B 24

// Status and Control
#define STATUS_LED_PIN  8
#define STATUS_LED_COUNT 2
#define START_BUTTON_PIN A0
#define DEBUG_LED_PIN   2

// ===== DRIVE MOTOR MANAGEMENT =====
class DriveSystem {
private:
  int motorPin;
  int currentPower;
  
public:
  DriveSystem(int pin) : motorPin(pin), currentPower(0) {}
  
  void initialize() {
    pinMode(motorPin, OUTPUT);
    analogWrite(motorPin, 0);
  }
  
  void setPower(int power) {
    power = constrain(power, 0, 255);
    currentPower = power;
    analogWrite(motorPin, power);
  }
  
  void halt() {
    setPower(0);
  }
  
  int getCurrentPower() { return currentPower; }
};

// ===== STEERING SERVO MANAGEMENT =====
class SteeringSystem {
private:
  Servo steeringServo;
  int currentPosition;
  const int CENTER_POSITION = 90;
  const int LEFT_BOUNDARY = 50;   
  const int RIGHT_BOUNDARY = 130; 
  
public:
  void initialize() {
    steeringServo.attach(STEERING_SERVO_PIN);
    currentPosition = CENTER_POSITION;
    steeringServo.write(CENTER_POSITION);
    delay(500); // Allow servo to reach position
    
    Serial.print("Steering initialized at: ");
    Serial.println(CENTER_POSITION);
  }
  
  void setPosition(int position) {
    position = constrain(position, LEFT_BOUNDARY, RIGHT_BOUNDARY);
    currentPosition = position;
    steeringServo.write(position);
  }
  
  void centerSteering() {
    setPosition(CENTER_POSITION);
  }
  
  void steerLeft(int amount) {
    setPosition(CENTER_POSITION - amount);
  }
  
  void steerRight(int amount) {
    setPosition(CENTER_POSITION + amount);
  }
  
  int getPosition() { return currentPosition; }
};

// ===== VISUAL STATUS INDICATOR =====
class StatusDisplay {
private:
  Adafruit_NeoPixel ledStrip;
  
public:
  StatusDisplay() : ledStrip(STATUS_LED_COUNT, STATUS_LED_PIN, NEO_GRB + NEO_KHZ800) {}
  
  void initialize() {
    ledStrip.begin();
    ledStrip.show(); 
    Serial.println("Status display initialized");
  }
  
  void setAllLEDs(uint8_t r, uint8_t g, uint8_t b) {
    for(int i = 0; i < STATUS_LED_COUNT; i++) {
      ledStrip.setPixelColor(i, ledStrip.Color(r, g, b));
    }
    ledStrip.show();
  }
  
  void setSingleLED(int index, uint8_t r, uint8_t g, uint8_t b) {
    if(index >= 0 && index < STATUS_LED_COUNT) {
      ledStrip.setPixelColor(index, ledStrip.Color(r, g, b));
      ledStrip.show();
    }
  }
  
  void clearDisplay() { setAllLEDs(0, 0, 0); }
  void showRed() { setAllLEDs(255, 0, 0); }
  void showGreen() { setAllLEDs(0, 255, 0); }
  void showBlue() { setAllLEDs(0, 0, 255); }
  void showOrange() { setAllLEDs(255, 165, 0); }
  void showWhite() { setAllLEDs(255, 255, 255); }
  
  void adjustBrightness(uint8_t level) {
    ledStrip.setBrightness(level);
    ledStrip.show();
  }
  
  void flashPattern(uint8_t r, uint8_t g, uint8_t b, int duration = 500) {
    setAllLEDs(r, g, b);
    delay(duration);
    clearDisplay();
    delay(duration);
  }
};

// ===== RGB COLOR DETECTION SYSTEM =====
class ColorDetectionSystem {
private:
  // Detection thresholds for TCS3200 sensor
  struct ColorThresholds {
    int redMin, redMax;
    int greenMin, greenMax;  
    int blueMin, blueMax;
  };
  
  ColorThresholds blueBlockThresh = {50, 100, 50, 100, 150, 255};
  ColorThresholds orangeBlockThresh = {150, 255, 100, 180, 50, 120};
  
public:
  enum DetectedColor { NO_COLOR, BLUE_BLOCK, ORANGE_BLOCK };
  
  void initialize() {
    pinMode(RGB_S0_PIN, OUTPUT);
    pinMode(RGB_S1_PIN, OUTPUT);
    pinMode(RGB_S2_PIN, OUTPUT);
    pinMode(RGB_S3_PIN, OUTPUT);
    pinMode(RGB_OUT_PIN, INPUT);
    
    // Configure frequency scaling to 20%
    digitalWrite(RGB_S0_PIN, HIGH);
    digitalWrite(RGB_S1_PIN, LOW);
  }
  
  int measureChannel(char channel) {
    // Configure photodiode filters
    switch(channel) {
      case 'R':
        digitalWrite(RGB_S2_PIN, LOW);
        digitalWrite(RGB_S3_PIN, LOW);
        break;
      case 'G':
        digitalWrite(RGB_S2_PIN, HIGH);
        digitalWrite(RGB_S3_PIN, HIGH);
        break;
      case 'B':
        digitalWrite(RGB_S2_PIN, LOW);
        digitalWrite(RGB_S3_PIN, HIGH);
        break;
    }
    
    delayMicroseconds(100);
    return pulseIn(RGB_OUT_PIN, LOW, 50000);
  }
  
  DetectedColor analyzeColor() {
    int redValue = measureChannel('R');
    int greenValue = measureChannel('G');
    int blueValue = measureChannel('B');
    
    // TCS3200: lower frequency indicates higher color intensity
    
    if (blueValue < blueBlockThresh.blueMax && 
        redValue > blueBlockThresh.redMin && 
        greenValue > blueBlockThresh.greenMin) {
      return BLUE_BLOCK;
    }
    
    if (redValue < orangeBlockThresh.redMax && 
        greenValue < orangeBlockThresh.greenMax && 
        blueValue > orangeBlockThresh.blueMin) {
      return ORANGE_BLOCK;
    }
    
    return NO_COLOR;
  }
};

// ===== DISTANCE MEASUREMENT ARRAY =====
class ProximitySensorArray {
private:
  int leftTrigPin, leftEchoPin;
  int rightTrigPin, rightEchoPin;
  int frontTrigPin, frontEchoPin;
  
  int performSingleMeasurement(int trigPin, int echoPin) {
    digitalWrite(trigPin, LOW);
    delayMicroseconds(2);
    digitalWrite(trigPin, HIGH);
    delayMicroseconds(10);
    digitalWrite(trigPin, LOW);
    
    long duration = pulseIn(echoPin, HIGH, 30000);
    if (duration == 0) return 0;
    
    return duration * 0.034 / 2; // Convert to centimeters
  }
  
  int getStableMeasurement(int trigPin, int echoPin) {
    const int SAMPLE_COUNT = 5;
    const int MAX_DISTANCE = 100;
    const int MIN_DISTANCE = 2;
    const int VARIANCE_LIMIT = 10;
    
    int readings[SAMPLE_COUNT];
    int validReadings = 0;
    int sum = 0;

    for (int i = 0; i < SAMPLE_COUNT; i++) {
      int distance = performSingleMeasurement(trigPin, echoPin);
      delay(3); // Prevent interference
      
      if (distance >= MIN_DISTANCE && distance <= MAX_DISTANCE) {
        readings[validReadings++] = distance;  
        sum += distance;
      }
    }

    if (validReadings == 0) return 0;

    // Calculate average
    int average = sum / validReadings;

    // Filter outliers
    sum = 0;
    int filteredCount = 0;
    for (int i = 0; i < validReadings; i++) {
      if (abs(readings[i] - average) <= VARIANCE_LIMIT) {
        sum += readings[i];
        filteredCount++;
      }
    }

    if (filteredCount == 0) return 0;
    return sum / filteredCount;
  }
  
public:
  ProximitySensorArray(int lTrig, int lEcho, int rTrig, int rEcho, int fTrig, int fEcho) :
    leftTrigPin(lTrig), leftEchoPin(lEcho),
    rightTrigPin(rTrig), rightEchoPin(rEcho),
    frontTrigPin(fTrig), frontEchoPin(fEcho) {}
  
  void initialize() {
    pinMode(leftTrigPin, OUTPUT);
    pinMode(leftEchoPin, INPUT);
    pinMode(rightTrigPin, OUTPUT);
    pinMode(rightEchoPin, INPUT);
    pinMode(frontTrigPin, OUTPUT);
    pinMode(frontEchoPin, INPUT);
  }
  
  int getLeftDistance() {
    return getStableMeasurement(leftTrigPin, leftEchoPin);
  }
  
  int getRightDistance() {
    return getStableMeasurement(rightTrigPin, rightEchoPin);
  }
  
  int getFrontDistance() {
    return getStableMeasurement(frontTrigPin, frontEchoPin);
  }
  
  int getCenterDistance() {
    return getStableMeasurement(frontTrigPin, frontEchoPin);
  }
  
  // Select appropriate sensor based on navigation direction
  int getDirectionalDistance(int navDirection) {
    if (navDirection < 0) {
      // Left navigation, monitor right wall
      return getRightDistance();
    } else {
      // Right navigation, monitor left wall
      return getLeftDistance();
    }
  }
};

// ===== INERTIAL NAVIGATION SYSTEM =====
class InertialNavigator {
private:
  Adafruit_MPU6050 imuSensor;
  float currentHeading;
  float targetHeading;
  float calibrationOffset;
  float lastError;
  
  // Navigation control constants
  const float PROPORTIONAL_GAIN = 1.8;
  const float DERIVATIVE_GAIN = 1.2;
  
public:
  InertialNavigator() : currentHeading(0), targetHeading(0), calibrationOffset(0), lastError(0) {}
  
  bool initialize() {
    Wire.begin(); // Arduino Mega hardware I2C pins 20/21
    
    if (!imuSensor.begin()) {
      return false;
    }
    
    imuSensor.setAccelerometerRange(MPU6050_RANGE_8_G);
    imuSensor.setGyroRange(MPU6050_RANGE_500_DEG);
    imuSensor.setFilterBandwidth(MPU6050_BAND_21_HZ);
    
    performCalibration();
    return true;
  }
  
  void performCalibration() {
    const int CALIBRATION_SAMPLES = 250;
    float offsetSum = 0;
    
    for (int i = 0; i < CALIBRATION_SAMPLES; i++) {
      sensors_event_t accel, gyro, temp;
      imuSensor.getEvent(&accel, &gyro, &temp);
      offsetSum += gyro.gyro.z;
      delay(5);
    }
    
    calibrationOffset = offsetSum / CALIBRATION_SAMPLES;
  }
  
  void updateHeading(float deltaTime) {
    sensors_event_t accel, gyro, temp;
    imuSensor.getEvent(&accel, &gyro, &temp);
    
    float gyroRate = (gyro.gyro.z - calibrationOffset) * 57.2958; // Convert to deg/sec
    
    if (abs(gyroRate) > 0.1) { // Filter noise
      currentHeading += gyroRate * deltaTime;
    }
  }
  
  int calculateSteeringCorrection() {
    float headingError = targetHeading - currentHeading;
    float errorDerivative = headingError - lastError;
    
    int correction = -(int)(PROPORTIONAL_GAIN * headingError + DERIVATIVE_GAIN * errorDerivative);
    lastError = headingError;
    
    return correction;
  }
  
  void setTargetHeading(float target) { targetHeading = target; }
  float getCurrentHeading() { return currentHeading; }
  float getTargetHeading() { return targetHeading; }
  float getHeadingError() { return abs(targetHeading - currentHeading); }
};

// ===== WHEEL ROTATION TRACKER =====
class WheelEncoder {
private:
  volatile long rotationCount;
  static WheelEncoder* activeInstance;
  
  static void encoderInterrupt() {
    if (activeInstance) {
      activeInstance->rotationCount++;
    }
  }
  
public:
  WheelEncoder() : rotationCount(0) {
    activeInstance = this;
  }
  
  void initialize() {
    pinMode(ENCODER_PHASE_A, INPUT_PULLUP);
    pinMode(ENCODER_PHASE_B, INPUT_PULLUP);
    attachInterrupt(digitalPinToInterrupt(ENCODER_PHASE_A), encoderInterrupt, RISING);
  }
  
  long getRotationCount() { return rotationCount; }
  void resetCount() { rotationCount = 0; }
  
  float calculateDistance() {
    const float WHEEL_CIRCUMFERENCE = 19.48; // cm
    const float PULSES_PER_ROTATION = 341.2; // Encoder resolution
    return (rotationCount * WHEEL_CIRCUMFERENCE) / PULSES_PER_ROTATION;
  }
};

// Static instance definition
WheelEncoder* WheelEncoder::activeInstance = nullptr;

// ===== AUTONOMOUS NAVIGATION CONTROLLER =====
class AutonomousNavigator {
private:
  DriveSystem driveMotor;
  SteeringSystem steeringServo;
  StatusDisplay statusLEDs;
  ColorDetectionSystem colorSensor;
  ProximitySensorArray distanceSensors;
  InertialNavigator headingControl;
  WheelEncoder motionTracker;
  
  // Navigation state management
  enum NavigationMode { CRUISING, MANEUVERING, ADJUSTING };
  NavigationMode currentMode;
  
  int navigationDirection; // -1 = left course, 1 = right course, 0 = undetermined
  int completedManeuvers;
  bool maneuverInProgress;
  unsigned long lastUpdateTime;
  unsigned long lastAdjustmentTime;
  
  // Speed parameters
  int cruisingSpeed = 70;
  int maneuverSpeed = 150;
  
public:
  AutonomousNavigator() : 
    driveMotor(DRIVE_MOTOR_PIN),
    distanceSensors(DIST_LEFT_TRIG, DIST_LEFT_ECHO, DIST_RIGHT_TRIG, DIST_RIGHT_ECHO, DIST_FRONT_TRIG, DIST_FRONT_ECHO),
    currentMode(CRUISING),
    navigationDirection(0),
    completedManeuvers(0),
    maneuverInProgress(false),
    lastUpdateTime(0),
    lastAdjustmentTime(0) {}
  
  bool initializeAllSystems() {
    Serial.begin(115200);
    
    driveMotor.initialize();
    steeringServo.initialize();
    statusLEDs.initialize();
    colorSensor.initialize();
    distanceSensors.initialize();
    motionTracker.initialize();
    
    if (!headingControl.initialize()) {
      Serial.println("Failed to initialize heading control!");
      return false;
    }
    
    pinMode(DEBUG_LED_PIN, OUTPUT);
    pinMode(START_BUTTON_PIN, INPUT);
    
    Serial.println("All systems initialized successfully");
    return true;
  }
  
  void waitForStartSignal() {
    Serial.println("Waiting for start signal...");
    digitalWrite(DEBUG_LED_PIN, HIGH);
    statusLEDs.showRed(); // Red indicates waiting
    
    while (!digitalRead(START_BUTTON_PIN)) {
      delay(10);
    }
    
    digitalWrite(DEBUG_LED_PIN, LOW);
    statusLEDs.showGreen(); // Green indicates ready
    delay(1000);
    statusLEDs.clearDisplay();
    Serial.println("Navigation commenced...");
  }
  
  void executeNavigationCycle() {
    unsigned long currentTime = millis();
    if (currentTime - lastUpdateTime < 30) return; // 33Hz update rate
    
    float timeStep = (currentTime - lastUpdateTime) / 1000.0;
    lastUpdateTime = currentTime;
    
    headingControl.updateHeading(timeStep);
    
    switch (currentMode) {
      case CRUISING:
        performCruisingBehavior();
        break;
      case MANEUVERING:
        performManeuveringBehavior();
        break;
      case ADJUSTING:
        performAdjustingBehavior();
        break;
    }
    
    checkForMissionCompletion();
  }
  
private:
  void performCruisingBehavior() {
    driveMotor.setPower(cruisingSpeed);
    
    // Apply heading correction
    int steeringAdjustment = headingControl.calculateSteeringCorrection();
    steeringServo.setPosition(90 + steeringAdjustment);
    
    // Establish navigation direction on first color detection
    if (navigationDirection == 0) {
      ColorDetectionSystem::DetectedColor blockColor = colorSensor.analyzeColor();
      if (blockColor != ColorDetectionSystem::NO_COLOR && !maneuverInProgress) {
        determineNavigationDirection(blockColor);
        return;
      }
    }
    
    // Monitor for obstacle requiring maneuver
    checkForObstacleManeuver();
    
    // Perform path centering corrections
    performPathCentering();
  }
  
  void determineNavigationDirection(ColorDetectionSystem::DetectedColor color) {
    if (completedManeuvers == 0) {
      // Establish permanent navigation direction
      navigationDirection = (color == ColorDetectionSystem::BLUE_BLOCK) ? -1 : 1;
      Serial.print("Navigation direction established: ");
      Serial.println(navigationDirection == -1 ? "LEFT course (Blue)" : "RIGHT course (Orange)");
      Serial.println("Switching to obstacle-based navigation");
    }
    
    // After direction establishment, ignore color detection
  }
  
  void performManeuveringBehavior() {
    // Engine control during maneuvers
    if (completedManeuvers < 12) {
      driveMotor.setPower(maneuverSpeed);
    }
    
    int steeringAdjustment = headingControl.calculateSteeringCorrection();
    steeringServo.setPosition(90 + steeringAdjustment);
    
    if (headingControl.getHeadingError() < 3.0) {
      // Maneuver completed
      digitalWrite(DEBUG_LED_PIN, LOW);
      statusLEDs.clearDisplay();
      maneuverInProgress = false;
      currentMode = CRUISING;
      
      // Resume normal speed only if not final maneuver
      if (completedManeuvers < 12) {
        driveMotor.setPower(cruisingSpeed);
      }
      
      Serial.println("Maneuver completed");
    }
  }
  
  // Detect obstacles requiring navigation maneuvers
  void checkForObstacleManeuver() {
    if (navigationDirection == 0 || maneuverInProgress) return;
    
    int frontObstacleDistance = distanceSensors.getFrontDistance();
    
    // Initiate maneuver when obstacle detected
    if (frontObstacleDistance > 0 && frontObstacleDistance < 50) {
      completedManeuvers++;
      digitalWrite(DEBUG_LED_PIN, HIGH);
      
      // Visual feedback based on maneuver direction
      if (navigationDirection == -1) {
        statusLEDs.showBlue(); // Blue for left maneuvers
      } else {
        statusLEDs.showOrange(); // Orange for right maneuvers
      }
      
      // Calculate new heading target
      float newHeading = headingControl.getTargetHeading() + (90.0 * -navigationDirection);
      headingControl.setTargetHeading(newHeading);
      
      // Special handling for final maneuver
      if (completedManeuvers >= 13) {
        driveMotor.halt(); // Engine off for final maneuver
        Serial.println("FINAL MANEUVER - Engine shutdown");
      } else {
        driveMotor.setPower(maneuverSpeed);
      }
      
      maneuverInProgress = true;
      currentMode = MANEUVERING;
      
      Serial.print("Obstacle at ");
      Serial.print(frontObstacleDistance);
      Serial.print("cm - Maneuver ");
      Serial.print(completedManeuvers);
      Serial.print(" initiated (");
      Serial.print(navigationDirection == -1 ? "LEFT" : "RIGHT");
      Serial.println(")");
    }
  }
  
  // Maintain centered path between boundaries
  void performPathCentering() {
    if (maneuverInProgress || navigationDirection == 0) return;
    if (millis() - lastAdjustmentTime < 800) return;
    
    // Read bilateral distance sensors
    int leftBoundary = distanceSensors.getLeftDistance();
    int rightBoundary = distanceSensors.getRightDistance();
    
    if (leftBoundary == 0 || rightBoundary == 0) return;
    
    const int CENTERING_MAGNITUDE = 6;
    const int CENTERING_TOLERANCE = 8;
    
    int boundaryDifference = leftBoundary - rightBoundary;
    
    if (abs(boundaryDifference) > CENTERING_TOLERANCE) {
      float adjustedHeading;
      if (boundaryDifference > 0) {
        // Closer to left boundary, adjust rightward
        adjustedHeading = headingControl.getTargetHeading() + CENTERING_MAGNITUDE;
        Serial.println("Path centering: adjusting right");
      } else {
        // Closer to right boundary, adjust leftward
        adjustedHeading = headingControl.getTargetHeading() - CENTERING_MAGNITUDE;
        Serial.println("Path centering: adjusting left");
      }
      
      headingControl.setTargetHeading(adjustedHeading);
      lastAdjustmentTime = millis();
    }
  }
  
  void performAdjustingBehavior() {
    // Reserved for future correction algorithms
    currentMode = CRUISING;
  }
  
  void checkForMissionCompletion() {
    if (completedManeuvers >= 12) {
      Serial.println("Mission accomplished! System shutdown...");
      statusLEDs.showWhite(); // White indicates mission complete
      
      // Complete stop
      steeringServo.centerSteering();
      driveMotor.halt();
      
      Serial.println("Vehicle stopped successfully!");
      statusLEDs.flashPattern(0, 255, 0, 1000); // Victory celebration
      while (true) { delay(1000); } // Infinite hold
    }
  }
};

// ===== SYSTEM INITIALIZATION =====
AutonomousNavigator vehicleController;

// ===== MAIN PROGRAM EXECUTION =====
void setup() {
  if (!vehicleController.initializeAllSystems()) {
    Serial.println("Critical system failure during initialization!");
    while (true) { delay(1000); }
  }
  
  vehicleController.waitForStartSignal();
}

void loop() {
  vehicleController.executeNavigationCycle();
}

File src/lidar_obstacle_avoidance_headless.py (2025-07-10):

#!/usr/bin/env python3
"""
LiDAR Obstacle Avoidance System - Headless Version
Designed to run automatically on system startup without user interaction.
Integrates LiDAR HTTP server, motor control (eng.py), and servo rotation (rot.py)
Automatically rotates when obstacle detected at 180 degrees with distance < 1500mm

Copyright (C) 2025  Alexis Martinez

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
import time
import threading
import logging
import requests
import RPi.GPIO as GPIO
from typing import Optional, Dict, Any
import json
import subprocess
import os
import sys
import signal

# Configure logging for headless operation
log_dir = "/var/log/wro"
os.makedirs(log_dir, exist_ok=True)

logging.basicConfig(
    level=logging.INFO,
    format='%(asctime)s - %(levelname)s - %(message)s',
    handlers=[
        logging.FileHandler(f"{log_dir}/obstacle_avoidance.log"),
        logging.StreamHandler(sys.stdout)  # Also log to stdout for systemd journal
    ]
)
logger = logging.getLogger(__name__)

class LidarObstacleAvoidanceHeadless:
    """Headless obstacle avoidance system using LiDAR, motor control, and servo rotation"""
    
    def __init__(self, lidar_server_url: str = "http://localhost:5000"):
        self.lidar_server_url = lidar_server_url
        self.running = False
        self.monitor_thread = None
        self.lidar_server_process = None
        self.shutdown_requested = False
        
        # Setup signal handlers for graceful shutdown
        signal.signal(signal.SIGINT, self._signal_handler)
        signal.signal(signal.SIGTERM, self._signal_handler)
        
        # GPIO setup
        GPIO.setmode(GPIO.BCM)
        GPIO.setwarnings(False)
        
        # Motor control setup (from eng.py)
        self.MOSFET_GPIO = 18
        self.PWM_FREQUENCY = 1000  # 1 kHz
        GPIO.setup(self.MOSFET_GPIO, GPIO.OUT)
        self.motor_pwm = GPIO.PWM(self.MOSFET_GPIO, self.PWM_FREQUENCY)
        self.motor_pwm.start(0)  # Start with motor off
        
        # Servo control setup (adapted from rot.py)
        # Note: rot.py uses BOARD mode pin 16, which is BCM pin 23
        self.SERVO_GPIO = 23  # BCM pin 23 (BOARD pin 16)
        GPIO.setup(self.SERVO_GPIO, GPIO.OUT)
        self.servo_pwm = GPIO.PWM(self.SERVO_GPIO, 50)  # 50Hz for servo
        self.servo_pwm.start(0)
        
        # Configuration parameters
        self.OBSTACLE_THRESHOLD = 1500  # mm
        self.TARGET_ANGLE = 180  # degrees to monitor (front robot)
        self.ANGLE_TOLERANCE = 30.0  # degrees tolerance around target angle
        self.SCAN_INTERVAL = 0.001  # seconds between scans
        
        # Steering angles (using rot.py mapping)
        self.NORMAL_STEERING = 90  # Center position (0-180 range)
        self.AVOID_STEERING = 45  # Turn right to avoid obstacle
        
        # State variables
        self.obstacle_detected = False
        self.current_servo_angle = self.NORMAL_STEERING
        self.motor_speed = 0
        self.lap_count = 0
        self.max_laps = 7
        self.avoiding_obstacle = False
        self.avoidance_start_time = None
        
        logger.info("🤖 LiDAR Obstacle Avoidance System (Headless) initialized")
        logger.info(f"Motor GPIO: {self.MOSFET_GPIO}, Servo GPIO: {self.SERVO_GPIO}")
    
    def _signal_handler(self, signum, frame):
        """Handle shutdown signals gracefully"""
        logger.info(f"🛑 Received signal {signum}, initiating graceful shutdown...")
        self.shutdown_requested = True
        self.stop()
    
    def _start_lidar_server(self) -> bool:
        """Start the LiDAR HTTP server as a subprocess"""
        try:
            # Check if server is already running
            try:
                response = requests.get(f"{self.lidar_server_url}/api/status", timeout=2)
                if response.status_code == 200:
                    logger.info("✅ LiDAR HTTP server already running")
                    return True
            except:
                pass  # Server not running, we'll start it
            
            # Start the LiDAR Flask server
            server_script = "/home/pi/wro/lidar_flask.py"
            if not os.path.exists(server_script):
                logger.error(f"❌ LiDAR server script not found: {server_script}")
                return False
            
            logger.info("🚀 Starting LiDAR HTTP server...")
            
            # Start the server as a subprocess
            self.lidar_server_process = subprocess.Popen(
                [sys.executable, server_script],
                stdout=subprocess.PIPE,
                stderr=subprocess.PIPE,
                cwd="/home/pi/wro"
            )
            
            # Wait for server to start
            for attempt in range(30):  # Wait up to 30 seconds
                try:
                    response = requests.get(f"{self.lidar_server_url}/api/status", timeout=2)
                    if response.status_code == 200:
                        logger.info("✅ LiDAR HTTP server started successfully")
                        return True
                except:
                    time.sleep(1)
                    continue
            
            logger.error("❌ LiDAR HTTP server failed to start within 30 seconds")
            return False
            
        except Exception as e:
            logger.error(f"❌ Error starting LiDAR server: {e}")
            return False
    
    def _stop_lidar_server(self):
        """Stop the LiDAR HTTP server subprocess"""
        if self.lidar_server_process:
            try:
                logger.info("🛑 Stopping LiDAR HTTP server...")
                self.lidar_server_process.terminate()
                
                # Wait for graceful shutdown
                try:
                    self.lidar_server_process.wait(timeout=5)
                except subprocess.TimeoutExpired:
                    logger.warning("⚠️ LiDAR server didn't stop gracefully, force killing...")
                    self.lidar_server_process.kill()
                    self.lidar_server_process.wait()
                
                logger.info("✅ LiDAR HTTP server stopped")
                self.lidar_server_process = None
            except Exception as e:
                logger.error(f"❌ Error stopping LiDAR server: {e}")
    
    def start(self):
        """Start the obstacle avoidance system"""
        if self.running:
            logger.warning("⚠️ System already running")
            return False
        
        logger.info("🚀 Starting LiDAR Obstacle Avoidance System (Headless Mode)")
        
        # Start LiDAR HTTP server
        if not self._start_lidar_server():
            logger.error("❌ Failed to start LiDAR server, aborting")
            return False
        
        # Ensure LiDAR is running
        self._ensure_lidar_running()
        
        self.running = True
        
        # Start monitoring thread
        self.monitor_thread = threading.Thread(target=self._monitor_loop, daemon=True)
        self.monitor_thread.start()
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

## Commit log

2025-07-01 Rename raspberrypi 4 .jpeg to raspberrypi4.jpeg
2025-09-30 Add complete robot controller implementation
    This file contains the complete implementation of the WRO Future Engineers Robot Controller, including hardware configuration, sensor integration, motor control, and state management for a racing tas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

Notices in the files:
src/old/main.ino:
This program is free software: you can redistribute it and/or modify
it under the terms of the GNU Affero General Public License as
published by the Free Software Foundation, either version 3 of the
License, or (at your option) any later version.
